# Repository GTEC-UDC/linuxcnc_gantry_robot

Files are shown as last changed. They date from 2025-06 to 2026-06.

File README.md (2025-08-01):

# LinuxCNC Gantry Robot System

A large high-precision 3-axis gantry robot system using [LinuxCNC](https://www.linuxcnc.org), integrated with [Mesa Electronics](https://store.mesanet.com/) interface cards and [igus® dryve D1](https://www.igus.eu/product/D1) motor controllers.

The system was developed from our [LinuxCNC motor control testbed](https://github.com/GTEC-UDC/linuxcnc_testbed), which ensured the main components of the system were able to work reliably.

The repository includes a **custom calibration solution** that leverages an existing [OptiTrack](https://optitrack.com/) motion capture system in the installation room to measure and compensate for errors in the gantry movement. Using this solution the gantry robot can achieve sub-centimeter precision across the entire work envelope.

<div align="center">






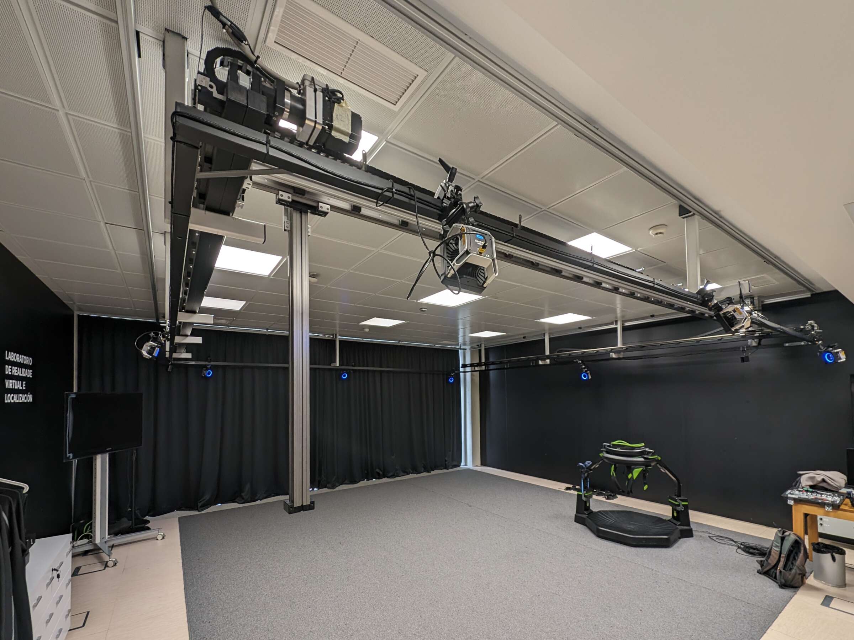
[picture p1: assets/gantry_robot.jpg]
Gantry Robot System


</div>

## Key Features

- **3-Axis Control**: X, Y, Z linear axes.
- **Large Work Envelope**: 5.3m (X) × 5.2m (Y) × 1m (Z) working volume.
- **Real-time Coordination**: Precise real-time motion using LinuxCNC with MESA interface cards and igus® dryve D1 motor controllers.
- **Closed Loop Control**: High-precision encoder feedback for accurate positioning using closed loop control.
- **Visual Status Indicators**: Custom LED status indicators.
- **Positioning calibration**: Software to analyze OptiTrack measurements and custom LinuxCNC kinematics module for compensation of positioning errors.
- **Heavy Duty**: Built with igus® self-lubricating linear units enabling lifelong operation of the moving parts without external lubrication.

## Documentation

The following documentation is provided in this repository:

- **Technical Documentation**: [Sphinx](https://www.sphinx-doc.org) documentation sources of the system documentation in [docs/](docs/). The documentation has been prepared to be built in HTML and PDF formats. To build the documentation follow the instructions below:

  1. **Prepare the environment**:

     ```bash
     cd docs
     uv venv && uv sync && source .venv/bin/activate
     ```

  2. **Build the documentation**:

     - HTML: `make html`

       The HTML documentation index file will be saved in `docs/build/html/index.html`.

     - PDF (requires a LaTeX installation with LuaLaTeX): `make latexpdf`

       The PDF file will be saved in `docs/build/latex/linuxcnc_gantry_robot.pdf`.

- **Electrical Installation**: KiCAD electrical schematics in [electrical_installation/schematics/](electrical_installation/schematics/).

## Positioning calibration

The gantry robot can be calibrated to compensate for positioning errors using an existing OptiTrack motion capture system in the installation room. For this, the repository provides the following software:

- **Custom `calibxyzkins` LinuxCNC Kinematics Module** in [linuxcnc/components/linuxcnc_calibrated_xyz_kins/](linuxcnc/components/linuxcnc_calibrated_xyz_kins/): compensates for the positioning errors in real-time
- **Calibration Analysis Software** in [calibration/](calibration/): Python scripts for processing the OptiTrack data and generating the calibration parameters

## Hardware Components

| Component | Model | Quantity | Function |
|---|---|---|---|
| **Control Computer** | PC running [LinuxCNC](https://www.linuxcnc.org) | 1 | Real-time motor coordination |
| **Motor Controllers** | [igus® dryve D1](https://www.igus.eu/product/D1) | 4 | Individual motor control |
| **Main Interface** | [MESA 7I96S](https://store.mesanet.com/index.php?route=product/product&product_id=374) | 1 | Ethernet-LinuxCNC bridge and stepper motor control |
| **I/O Expansion** | [MESA 7I77](https://store.mesanet.com/index.php?route=product/product&product_id=120) | 1 | Analog control for brushless motors and I/O signals |
| **X-Axis Motor** | [igus® MOT-EC-86-C-I-A](https://www.igus.eu/product/MOT-EC-86-C-I-A) | 2 | NEMA 34 brushless with 1000 PPR encoder |
| **Y-Axis Motor** | [igus® MOT-EC-86-C-I-A](https://www.igus.eu/product/MOT-EC-86-C-I-A) | 1 | NEMA 34 brushless with 1000 PPR encoder |
| **Z-Axis Motor** | [igus® MOT-AN-S-060-035-060-M-C-AAAC](https://www.igus.eu/product/MOT-AN-S-060-035-060-M-C-AAAC) | 1 | NEMA 24 stepper with 500 PPR encoder |
| **Emergency Stop** | Push-button with NO/NC contacts | 1 | System safety shutdown |
| **Limit Switches** | [igus® proximity switch](https://www.igus.eu/product/drylin_E_ini_kits_plastic_housing) | 4 | Position boundary detection |
| **48V Power Supply** | [MEAN WELL SDR-960-48](https://www.meanwell.com/webapp/product/search.aspx?prod=SDR-960) | 3 | Brushles motors power |
| **24V Power Supply** | [MEAN WELL SDR-240-24](https://www.meanwell.com/webapp/product/search.aspx?prod=SDR-240) | 1 | Stepper motor power |
| **24V Power Supply** | Generic power supply | 1 | igus® Drive D1 logic and MESA 7I77 field power |
| **5V Power Supply** | [MEAN WELL MDR-20-5](https://www.meanwell.com/webapp/product/search.aspx?prod=MDR-20) | 1 | MESA 7I77 field I/O logic power |

## System Architecture

Prototype System

## Repository Structure

```txt
gantry-robot/
├── README.md                    # This file
├── assets/                      # Pictures and videos
├── docs/                        # Technical documentation
├── igus-dryve/                  # igus® dryve D1 configuration files
├── linuxcnc/                    # LinuxCNC configuration files
│   ├── configs/                 # Machine configurations
│   └── components/              # Custom LinuxCNC components
├── calibration/                 # Calibration code and measurements
│   ├── src/                     # Python analysis and calibration tools
│   └── measurements/            # Gantry robot and OptiTrack measurements
└── electrical_installation/     # Electrical documentation
    ├── schematics/              # KiCAD electrical diagrams
    └── photos/                  # Electrical installation photos
```

## License

This project contains multiple components with different licenses.

### General License (unless otherwise specified)

<a rel="license" href="http://creativecommons.org/licenses/by-sa/4.0/">

</a>

[LinuxCNC Gantry Robot System](https://github.com/GTEC-UDC/linuxcnc_gantry_robot) © 2025 by [Tomás Domínguez Bolaño](https://orcid.org/0000-0001-7470-0315), [Valentín Barral Vales](https://orcid.org/0000-0001-8750-7960), [Carlos José Escudero Cascón](https://orcid.org/0000-0002-3877-1332), and [José Antonio García Naya](https://orcid.org/0000-0002-1944-4678) (CITIC Research Center, University of A Coruña, Spain) is licensed under [Creative Commons Attribution-ShareAlike 4.0 International](https://creativecommons.org/licenses/by-sa/4.0/) (CC BY-SA 4.0). To view a copy of this license, see the [LICENSE](LICENSE) file or visit <https://creativecommons.org/licenses/by-sa/4.0/>.

### Documentation License ([docs/](docs/))

Copyright © 2000-2022 LinuxCNC.org\
Copyright © 2025 Tomás Domínguez Bolaño, Valentín Barral Vales, Carlos José Escudero Cascón, and José Antonio García Naya.

Permission is granted to copy, distribute and/or modify this document
under the terms of the GNU Free Documentation License, Version 1.3
or any later version published by the Free Software Foundation;
with no Invariant Sections, no Front-Cover Texts, and no Back-Cover Texts.
A copy of the license is included in the section entitled "GNU Free Documentation License".

### Software Licenses

- **LinuxCNC Components** (`linuxcnc/components/`): [GPL v2 or later](https://www.gnu.org/licenses/old-licenses/gpl-2.0.html)
- **Calibration Source Code** (`calibration/src/`): [MIT License](https://opensource.org/licenses/MIT)

## Acknowledgments

This work has been supported by grant PID2022-137099NB-C42 (MADDIE) and by project TED2021-130240B-I00 (IVRY) funded by MCIN/AEI/10.13039/501100011033 and the European Union NextGenerationEU/PRTR.

<div align="center">
  Acknowledgements logos
</div>

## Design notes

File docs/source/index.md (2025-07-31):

# {{project}}

A large high-precision 3-axis gantry robot system using [LinuxCNC](https://www.linuxcnc.org), integrated with [Mesa Electronics](https://store.mesanet.com/) interface cards and [igus® dryve D1](https://www.igus.eu/product/D1) motor controllers.

The system was developed from our [LinuxCNC motor control testbed](https://github.com/GTEC-UDC/linuxcnc_testbed), which ensured the main components of the system were able to work reliably.

The system includes a custom calibration solution that leverages an existing [OptiTrack](https://optitrack.com/) motion capture system in the installation room to measure and compensate for errors in the gantry movement. Using this solution the gantry robot can achieve sub-centimeter precision across the entire work envelope.

---

Copyright (C) 2000-2022 LinuxCNC.org\
Copyright (C) 2025 Tomás Domínguez Bolaño, Valentín Barral Vales, Carlos José Escudero Cascón, and José Antonio García Naya.

Permission is granted to copy, distribute and/or modify this document
under the terms of the GNU Free Documentation License, Version 1.3
or any later version published by the Free Software Foundation;
with no Invariant Sections, no Front-Cover Texts, and no Back-Cover Texts.
A copy of the license is included in the section entitled "GNU Free Documentation License".

---

This work has been supported by grant PID2022-137099NB-C42 (MADDIE) and by project TED2021-130240B-I00 (IVRY) funded by MCIN/AEI/10.13039/501100011033 and the European Union NextGenerationEU/PRTR.

:::{ext-image} images/logos/ack_logos.*
:width-html: 700px
:name: fig:ack_logos
:::

:::{only} html
<!-- -->
---
<!-- -->
:::

:::{toctree}
:maxdepth: 2
:numbered:
:caption: Table of Contents

doc/01_introduction/introduction.md
doc/02_igus_dryve_d1/00_index.md
doc/03_linuxcnc/00_index.md
doc/04_error_analysis_calibration/00_index.md
doc/05_calibxyzkins_module/00_index.md
:::

:::{raw} latex
% Do not show section numbers for the following sections in latex
\setcounter{secnumdepth}{-1}
:::

:::{toctree}
:maxdepth: 1

fdl-1.3.md
bibliography.md
:::

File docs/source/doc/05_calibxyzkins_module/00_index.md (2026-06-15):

(sec:calibxyzkins_module)=

# calibxyzkins - Calibrated XYZ Kinematics Module for LinuxCNC

The `calibxyzkins` module extends the standard LinuxCNC trivial kinematics module `trivkins` by applying a mathematical correction to compensate for systematic positioning errors in gantry robots and similar cartesian machines. This is particularly useful for correcting:

- Mechanical inaccuracies in manufacturing or assembly
- Structural deformations under load
- Non-perpendicular axes alignment
- Position-dependent errors

## Coordinate Transformation

The module implements a coordinate transformation that corrects the relationship between joint positions and actual machine coordinates using both linear and quadratic terms:

$[x', y', z']^T = \mathbf{A} [x, y, z]^T + \mathbf{B} [x^2, y^2, z^2]^T + \mathbf{c}$

Where:

- $(\cdot)^T$: Transpose operator
- $\mathbf{A}$: 3×3 linear transformation matrix (scaling, rotation, shear, etc.)
- $\mathbf{B}$: 3×3 quadratic transformation matrix (corrects non-linear distortions)
- $\mathbf{c}$: 3×1 offset vector (constant position offset)
- $x, y, z$: joint positions
- $x', y', z'$: axes coordinates

The default values of the parameters are:

- $\mathbf{A}$: 3x3 identity matrix
- $\mathbf{B}$: all zeros
- $\mathbf{c}$: all zeros

## Installation

Prerequisites:

- LinuxCNC development environment
- Standard build tools (make, gcc)

To build the module, run:

```bash
cd linuxcnc/components/linuxcnc_calibrated_xyz_kins
make
```

To install the module system-wide, run:

```bash
sudo make install
```

### Loading the Module

The module can be loaded as any other HAL component. Depending on the machine configuration, the `coordinates` and `kinstype` parameters can be used to specify the axis-to-joint mapping.

Examples:

- Basic usage (equivalent to `trivkins`):

  ```hal
  loadrt calibxyzkins
  ```

- Specify coordinate mapping:

  ```hal
  loadrt calibxyzkins coordinates=xyz
  ```

- Gantry configuration with duplicated Y axis:

  ```hal
  loadrt calibxyzkins coordinates=xyyz kinstype=B
  ```

## Module Parameters

- `coordinates`

  Specifies the axis-to-joint mapping, as in `trivkins`:
  
  - **coordinates=xyz**: Standard 3-axis mapping (X→joint0, Y→joint1, Z→joint2)
  - **coordinates=xyyz**: Gantry with dual Y motors (X→joint0, Y→joint1&joint2, Z→joint3)
  - **coordinates=xyzabc**: 6-axis machine. Note that calibration is only applied to the X, Y, and Z axes.

- `kinstype`

  Specifies the kinematics type, as in `trivkins`:
  
  - **kinstype=1**: KINEMATICS_IDENTITY (default)
  - **kinstype=B**: KINEMATICS_BOTH
  - **kinstype=F**: KINEMATICS_FORWARD_ONLY
  - **kinstype=I**: KINEMATICS_INVERSE_ONLY

## HAL Parameters

**Calibration Matrix A (Linear Terms)**:

- `calibxyzkins.calib-a.xx` (float, RW, default: 1.0)
- `calibxyzkins.calib-a.xy` (float, RW, default: 0.0)
- `calibxyzkins.calib-a.xz` (float, RW, default: 0.0)
- `calibxyzkins.calib-a.yx` (float, RW, default: 0.0)
- `calibxyzkins.calib-a.yy` (float, RW, default: 1.0)
- `calibxyzkins.calib-a.yz` (float, RW, default: 0.0)
- `calibxyzkins.calib-a.zx` (float, RW, default: 0.0)
- `calibxyzkins.calib-a.zy` (float, RW, default: 0.0)
- `calibxyzkins.calib-a.zz` (float, RW, default: 1.0)

**Calibration Matrix B (Quadratic Terms)**:

- `calibxyzkins.calib-b.xx` (float, RW, default: 0.0)
- `calibxyzkins.calib-b.xy` (float, RW, default: 0.0)
- `calibxyzkins.calib-b.xz` (float, RW, default: 0.0)
- `calibxyzkins.calib-b.yx` (float, RW, default: 0.0)
- `calibxyzkins.calib-b.yy` (float, RW, default: 0.0)
- `calibxyzkins.calib-b.yz` (float, RW, default: 0.0)
- `calibxyzkins.calib-b.zx` (float, RW, default: 0.0)
- `calibxyzkins.calib-b.zy` (float, RW, default: 0.0)
- `calibxyzkins.calib-b.zz` (float, RW, default: 0.0)

**Calibration Vector c (Offset Terms)**:

- `calibxyzkins.calib-c.x` (float, RW, default: 0.0)
- `calibxyzkins.calib-c.y` (float, RW, default: 0.0)
- `calibxyzkins.calib-c.z` (float, RW, default: 0.0)

**Joint Limits**:

- `calibxyzkins.min-limit.x` (float, RW, default: -∞)
- `calibxyzkins.min-limit.y` (float, RW, default: -∞)
- `calibxyzkins.min-limit.z` (float, RW, default: -∞)
- `calibxyzkins.max-limit.x` (float, RW, default: +∞)
- `calibxyzkins.max-limit.y` (float, RW, default: +∞)
- `calibxyzkins.max-limit.z` (float, RW, default: +∞)

## HAL Pins

**Inverse Kinematics Solver Settings**:

- `calibxyzkins.max-iter` (u32, IO, default: 10)
  - Maximum number of Newton-Raphson iterations for the inverse kinematics.
- `calibxyzkins.tol` (float, IO, default: 1e-3)
  - Convergence tolerance for the inverse kinematics solver.

## Inverse Kinematics

The module uses the Newton-Raphson method to solve the inverse kinematics problem iteratively:

1. Initialize the $3 \times 1$ vector of joint positions $\mathbf{x}$ to the target position $\mathbf{x'}$ (bounded by joint limits if specified)
2. Perform Newton-Raphson iterations until convergence or max iterations reached:
   1. Compute residual: $\mathbf{r} = \mathbf{A} \, \mathbf{x} + \mathbf{B} \, \mathbf{x}^2 + \mathbf{c} - \mathbf{x'}$
   2. Return if convergence reached ($\|\mathbf{r}\|_2 < \text{tolerance}$).
   3. Compute Jacobian: $\mathbf{J} = \mathbf{A} + 2 \, \mathbf{B} \, \text{diag}(\mathbf{x})$
   4. Update joints: $\mathbf{x} := \mathbf{x} - \mathbf{J}^{-1} \mathbf{r}$

## Debugging

Verbose output of the inverse kinematics solver can be enabled by compiling the code with the `CALIB_XYZ_INVERSE_PRINT_ITER` macro defined.

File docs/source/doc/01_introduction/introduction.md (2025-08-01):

# Introduction

The gantry robot uses LinuxCNC as its control platform, integrated with Mesa Electronics interface boards and igus® dryve D1 motor controllers. It provides a displacement range of 5.3m (X) × 5.2m (Y) × 1m (Z), with a total work volume of approximately 6m (X) × 6m (Y) × 2m (Z). {numref}`fig:installation` shows a photograph of the gantry robot structure. The system diagram is shown in {numref}`fig:system_diagram`.

This system was developed from our LinuxCNC testbed (<https://github.com/GTEC-UDC/linuxcnc_testbed>). The system wiring diagram, detailing all components and their interconnections, is available in the {{project_url_link}}. Below, we detail the system's configuration, including the boards and components used.

:::{ext-figure} images/gantry_robot.*
:width-html: 75%
:name: fig:installation

Gantry robot structure.
:::

:::{ext-figure} images/system_diagram.*
:width-html: 75%
:name: fig:system_diagram

Gantry robot system diagram.
:::

## LinuxCNC

LinuxCNC, formerly known as the {{EMC}}, is a software system designed for the computer control of various machine tools, such as milling machines and lathes, as well as robots like PUMA and SCARA, and other computer-controlled machinery with up to nine axes. LinuxCNC is free, open-source software. Current versions are fully licensed under the [{{GPL}}](https://www.gnu.org/licenses/gpl.html) and [{{LGPL}}](https://gnu.org/licenses/lgpl.html).

In our system, LinuxCNC communicates with the igus® dryve D1 controllers via the MESA 7I96S and 7I77 boards. LinuxCNC is responsible for coordinating the operation of all motors, providing precise, real-time control over the system.

Detailed information on LinuxCNC's operation and configuration can be found in {numref}`sec:linuxcnc`.

(sec:hardware)=

## System Hardware

The following section describe the different hardware components of the system, such as the motor controllers, interface boards, motors, and safety systems. {numref}`fig:electrical_overview` belowshows the electrical cabinet and rack that house the interface boards, motor controllers, and power supplies.

:::{ext-figure} images/electrical_cabinet_and_rack.*
:width-html: 75%
:name: fig:electrical_overview

Electrical cabinet (left) containing the MESA interface boards and rack (right) containing the motor controllers and power supplies.
:::

### Main Components

- **Control Computer**: PC running [LinuxCNC](https://www.linuxcnc.org) for real-time motor coordination

- **4 Motor Controllers** [igus® dryve D1](https://www.igus.eu/product/D1): igus® dryve D1 can be used for controlling stepper, DC, and brushless motors in industrial and automation applications. The igus® dryve D1 supports the following communication methods with control systems:

  - **CANopen**: A communication protocol widely used in industrial automation systems, built upon the CAN bus (ISO 11898) standard.
  - **Modbus TCP**: A communication protocol extensively employed in industrial applications for data transmission over Ethernet networks using the TCP protocol.
  - **Analog and Digital Signals**: In addition to network communication options, the igus® dryve D1 can receive analog and digital signals for direct control.

    In this system, we communicate with the igus® dryve D1 controllers using MESA 7I96S and 7I77 boards using digital and analog signals. This setup enables LinuxCNC to have precise, real-time control over the motors' operation.

{numref}`fig:rack_interior` below shows the interior of the rack containing the four igus® dryve D1 motor controllers and the power supplies.

:::{ext-figure} images/rack.*
:width-html: 75%
:name: fig:rack_interior

Interior view of the rack showing the igus® dryve D1 motor controllers and power supplies.
:::

### Interface Boards

- **Main Board** [MESA 7I96S](https://store.mesanet.com/index.php?route=product/product&product_id=374): This board is the primary hardware interface between LinuxCNC and the igus® dryve D1 controllers. It connects to the computer running LinuxCNC via an Ethernet connection. Its main functions include:

  - Controlling the stepper motor by sending step and direction signals to its designated igus® dryve D1 controller.
  - Receiving input signals from limit switches.

- **Expansion Board** [MESA 7I77](https://store.mesanet.com/index.php?route=product/product&product_id=120): This board connects to the 7I96S board via a 25-pin flat cable. Its primary functions are:

  - Controlling the brushless motor by sending an analog speed signal to its corresponding igus® dryve D1 controller.
  - Receiving position feedback signals from motor encoders.
  - Receiving warning and error signals from the controllers.
  - Receiving the emergency stop signal when the emergency stop switch is activated.

{numref}`fig:electrical_cabinet` below shows the MESA 7I96S and 7I77 boards installed in the electrical cabinet.

:::{ext-figure} images/electrical_cabinet.*
:width-html: 75%
:name: fig:electrical_cabinet

Interior view of the electrical cabinet showing the MESA 7I96S and 7I77 interface boards.
:::

### Motors and Actuators

- **X-axis Motors**: 2 × [igus® MOT-EC-86-C-I-A](https://www.igus.eu/product/MOT-EC-86-C-I-A) - NEMA 34 brushless with integrated 1000 {{PPR}} encoder. A 10:1 reduction gear was installed on the motor shaft.

- **Y-axis Motor**: 1 × [igus® MOT-EC-86-C-I-A](https://www.igus.eu/product/MOT-EC-86-C-I-A) - NEMA 34 brushless with integrated 1000 {{PPR}} encoder. A 10:1 reduction gear was installed on the motor shaft.

- **Z-axis Motor**: 1 × [igus® MOT-AN-S-060-035-060-M-C-AAAC](https://www.igus.eu/product/motors-and-gears) - NEMA 24 stepper with 500 {{PPR}} encoder.

### Safety Systems and Sensors

- **Emergency Stop Switch**: This switch has both a normally closed and a normally open contact.

- **Limit Sensors**: 4 × igus® inductive sensors for position limit detection.

- **LED Indicators**: Custom indicators with red, yellow, and green LEDs, which provide a visual display of the system's status.

### Power Supply

- **48V Power Supplies**: 3 × [MEAN WELL SDR-960-48](https://www.meanwell.com/webapp/product/search.aspx?prod=SDR-960) for brushless motor power.
- **24V Power Supply**: 1 × [MEAN WELL SDR-240-24](https://www.meanwell.com/webapp/product/search.aspx?prod=SDR-240) for stepper motor power.
- **Additional 24V Power Supply**: For igus® dryve D1 logic and MESA 7I77 field power.
- **5V Power Supply**: [MEAN WELL MDR-20-5](https://www.meanwell.com/webapp/product/search.aspx?prod=MDR-20) for MESA 7I77 field I/O logic.

### Linear Units

The system is built with igus® self-lubricating linear units that enable lifetime operation of moving parts without external lubrication. The linear units details are the following:

- **X and Y axes**: [igus® ZLW-20120/20200](https://www.igus.eu/drive-technology/linear-axes-with-toothed-belts/technical-data) linear axes with toothed belts. The feed rate is 144 mm/rev.
- **Z axis**: [igus® SAW-1660](https://www.igus.eu/product/20908?artNr=SLW-1660-xxx) linear axis with lead screws. The feed rate is 4 mm/rev.

## Calibration System

This project includes the following calibration components:

- **Custom LinuxCNC kinematic module** `calibxyzkins` in `linuxcnc/components/linuxcnc_calibrated_xyz_kins`: enables real-time positioning error compensation.
- **Calibration analysis software** in `calibration/`: Python-based tools for processing OptiTrack data and generating calibration parameters.

This solution enables the gantry robot to achieve sub-centimeter precision throughout the entire working volume of 5.3m × 5.2m × 1m.

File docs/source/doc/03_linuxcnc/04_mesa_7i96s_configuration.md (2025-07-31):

# MESA 7I96S Board Configuration

## Flashing the Firmware

:::{note}
This process has already been completed and does not need to be repeated; it is described here solely for documentation purposes. For more information on configuring the MESA 7I96S board, please consult its manual.
:::

The MESA 7I96S board can be used standalone with its standard configuration. However, to use it with the MESA 7I77 board, we must flash the FPGA with the appropriate firmware. Various firmwares for the 7I96S board are available on the MESA website at <http://www.mesanet.com/software/parallel/7i96s.zip>.

To use the MESA 7I96S board with the MESA 7I77 board, we will use the `7i96s_7i77d.bin` firmware. First, power the board with 5 V via its P4 connector and connect it to the PC using an Ethernet cable. By default, the board's IP address is `192.168.1.121`. To verify connectivity, execute the following command:

```text
mesaflash -device 7i96s -addr 192.168.1.121
```

If successful, the `mesaflash` utility will detect the board and respond with the following output:

```text
ETH device 7I96S at ip=192.168.1.121
```

Finally, to flash the firmware to the board, execute the following command:

```text
mesaflash -device 7i96s -addr 192.168.1.121 -write 7i96s_7i77d.bin
```

## Network Configuration

The Beelink EQR6 mini computer used in our gantry robot system has two Ethernet ports, which allows for a dedicated network connection to the MESA 7I96S board. One port is used to connect the PC to the local network, while the other port is used for a direct connection to the MESA card. This setup provides isolation and dedicated bandwidth for the real-time communication with the motion control system.

## IP Address

The MESA 7I96S board has three options for setting the IP address: a default IP (`192.168.1.121`), an IP read from the EEPROM, and IP acquisition via the BOOTP network protocol. These options are selected using jumpers `W4` and `W5`, located on the bottom left of the board as shown in {numref}`fig:mesa_ip_selection`.

:::{figure} images/mesa/mesa_7i96s_left.*
:name: fig:mesa_ip_selection
:width: 80%

View of the left side of the MESA 7I96S board installed in the gantry robot system.
:::

The available IP configuration options are detailed in {numref}`tab:mesa_ip_selection`. Specifically, note the following:

- When jumpers `W4` and `W5` are in the (down, up) position, the IP address will be read from the EEPROM. The default IP address in the EEPROM is 10.10.10.10. This IP address can be changed using the `mesaflash` utility. For example, to set the IP in the EEPROM to 10.10.10.100, you would execute the following command:

  ```text
  mesaflash -device 7i96s -addr 192.168.1.121 -set ip=10.10.10.100
  ```

- When jumpers `W4` and `W5` are in the (up, up) position, the IP address will be set to 192.168.1.121, and the board will boot using the fallback configuration (see {numref}`sec:mesa7i96s_fallback`).

:::{csv-table} IP address configuration options on the MESA 7I96S board using jumpers ``W4`` and ``W5``.
:name: tab:mesa_ip_selection
:widths: auto
:header: W4, W5, IP Address

Down, Down, 192.168.1.121
Down, Up, Read from EEPROM
Up, Down, Obtained via BOOTP
Up, Up, 192.168.1.121 and use fallback conf.
:::

In our gantry robot system, jumpers `W4` and `W5` have been set to the (down, down) position, as shown in {numref}`fig:mesa_ip_selection`.

(sec:mesa7i96s_fallback)=

## Fallback Configuration

The MESA 7I96S board's flash memory contains two images: a main image and a fallback image. If the primary image becomes corrupted, the FPGA will load the fallback configuration, allowing a new main image to be written. Otherwise, the memory would have to be programmed via JTAG.

It is possible to force the board to boot using the fallback configuration by setting the IP selection jumpers `W4` and `W5` to the (up, up) position. In this boot mode, the card's IP address will be set to 192.168.1.121.

(sec:mesa7i96s_cable_power)=

## Expansion Connector 5 V Power Supply

The MESA 7I96S board has the capability to supply 5V power to the board connected to its expansion connector (P1), which in our case is the MESA 7I77. This option is controlled by jumper `W6`, located on the bottom of the board to the left of the expansion connector, as shown in {numref}`fig:mesa_ip_selection`. The settings are as follows:

- When jumper `W6` is in the up position, the MESA 7I96S board will provide power to the MESA 7I77 board through the expansion connector.
- When jumper `W6` is in the down position, the MESA 7I96S board will not provide power through the expansion connector; in this case, external power must be supplied to the MESA 7I77 board.

In our gantry robot system, the latter option was chosen, with jumper `W6` configured in the down position, as seen in {numref}`fig:mesa_ip_selection`. The MESA 7I77 board must also be configured appropriately, as explained in {numref}`sec:mesa7i77_power`.

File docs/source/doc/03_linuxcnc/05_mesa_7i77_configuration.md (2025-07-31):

# MESA 7I77 Board Configuration

(sec:mesa7i77_power)=

## 5 V Main Power

The MESA 7I77 board can draw its main 5V power either from the MESA 7I96S board or through its `TB1` connector. This power is needed for the encoders, analog outputs, and the RS-422 interface. The main power mode for the MESA 7I77 is selected using jumper `W5` as follows:

1. If `W5` is in the left position, power is supplied via the MESA 7I96S board. In this case, jumper `W6` on the MESA 7I96S board must be set to the up position.
2. If `W5` is in the right position, power must be supplied to the board externally through the `TB1` connector. In this case, jumper `W6` on the MESA 7I96S board must be set to the down position to prevent it from supplying power to the daughterboard.

:::{attention}
Supplying power to the MESA 7I77 board through the `TB1` connector with jumper `W5` in the left position can potentially damage the MESA 7I77 board, the MESA 7I96S board, the connection cable, and even the PC.
:::

In our gantry robot system, we chose to power the MESA 7I77 board via the `TB1` connector; therefore:

- Jumper `W6` on the MESA 7I96S board has been set to the down position, as shown in {numref}`fig:mesa_ip_selection`.
- Jumper `W5` on the MESA 7I77 board has been set to the right position, as shown in {numref}`fig:mesa7i77_left`.

:::{figure} images/mesa/mesa_7i77_left.*
:name: fig:mesa7i77_left

View of the left side of the MESA 7I77 board installed in the gantry robot system.
:::

## Digital Inputs and Outputs Power

In addition to the 5V main power, the MESA 7I77 board also requires supplementary power for its digital inputs and outputs through the `TB2` connector (see Figures {numref}`%s <fig:installation>` and {numref}`%s <fig:mesa7i77_right>`). The pinout for the `TB2` connector is provided in {numref}`tab:mesa7i77_tb2`.

:::{csv-table} Connections of the ``TB2`` connector of the MESA 7I77 board.
:name: tab:mesa7i77_tb2
:widths: auto
:header: Pin, Signal, Function

1 (bottom), `VFIELD`, `FIELD POWER`
2, `VFIELD`, `FIELD POWER`
3, `VFIELD`, `FIELD POWER`
4, `VFIELD`, `FIELD POWER`
5, `VIN`, `FIELD I/O LOGIC POWER`
6, Not connected, --
7, Not connected, --
8 (top), Ground, Reference of `VIN` & `VFIELD`
:::

As indicated in {numref}`tab:mesa7i77_tb2`, the board requires two power inputs in this configuration:

- `VFIELD`: This input supplies power to the outputs and determines the logic levels of the inputs, with a range of 5 V to 28 V.
- `VIN`: This input provides power to the input/output logic, with a range of 8 V to 32 V.

If `VFIELD` is between 8 V and 28 V, the same source can be used to power `VIN`. The board includes jumper W1, which, when placed in the left position, connects `VIN` with `VFIELD`. To use `VFIELD` values outside the `VIN` range (e.g., 5 V), you must place W1 in the right position to disconnect `VIN` and `VFIELD`, allowing for separate power supplies for `VIN` and `VFIELD`.

:::{attention}
The voltage at `VFIELD` must have a maximum rise rate of 10 V/ms to prevent damage to the board. This is a limitation of MOSFET transistors {cite}`toshiba2018impacts, toshiba2018mosfets, nexperia2023power, bai2003analysis`. Therefore, `VFIELD` must be connected directly to the power supply without using switches in the circuit.
:::

As stated in {numref}`sec:page_input_outputs`, the MESA 7I96S board can only use 5 V logic for step and direction signals. Therefore, the logic for both the igus® dryve D1 controllers and the MESA 7I77 board must also be 5 V. Thus, in our gantry robot system, jumper `W1` on the MESA 7I77 board has been set to the right position, the `VIN` input to 24 V, and the `VFIELD` input to 5 V, as shown in {numref}`fig:mesa7i77_right`.

::: {figure} images/mesa/mesa_7i77_right.*
:name: fig:mesa7i77_right

View of the right side of the MESA 7I77 board installed in the gantry robot system.
:::

## Encoder Input Modes

The MESA 7I77 board has six encoder inputs, each with individual A, B, and Z inputs. These inputs can be configured to operate with either differential or single-ended signals. Each encoder has three jumpers to configure the mode for its individual A, B, and Z inputs. Setting a jumper to the right position selects differential mode, while setting it to the left position selects single-ended mode. The list of jumpers for the individual inputs of each encoder is provided in {numref}`tab:encoder_jumpers`.

:::{table} Encoder configuration jumpers.
:name: tab:encoder_jumpers
:widths: auto

| Encoder | Jumper A  | Jumper B | Jumper C |
| --- | --- | --- | --- |
| 0 | W21 | W19 | W17 |
| 1 | W15 | W13 | W10 |
| 2 | W8 | W6 | W2 |
| 3 | W22 | W20 | W18 |
| 4 | W16 | W14 | W11 |
| 5 | W9 | W7 | W3 |
:::

In our gantry robot system each of the 4 motors has a differential encoder. Therefore, we set encoders 0 to 3 on the MESA 7I77 board to differential mode. {numref}`fig:mesa7i77_left` shows the location of the jumpers for encoders 0 to 3 on the MESA 7I77 board.

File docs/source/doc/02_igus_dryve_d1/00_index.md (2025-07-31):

# igus® dryve D1 Controllers

:::{important}
For the gantry robot development we used the igus® dryve D1 controllers with firmware version `dryve-D1-1-20240927` and their operating manual with version `3.1`.
:::

In this section, we will detail the configuration of the igus® dryve D1 controllers for our gantry robot. The robot uses 4 motors, each with its own controller:

- **X1 axis**: igus® MOT-EC-86-C-I-A brushless motor with 1000 {{PPR}} encoder and 10:1 reduction gear.
- **X2 axis**: identical to X1
- **Y axis**: identical to X1 and X2
- **Z axis**: igus® MOT-AN-S-060-035-060-M-C-AAAC stepper motor with 500 {{PPR}} encoder.

To configure each controller, connect it to a PC via an Ethernet cable. If you do not know a controller's IP address, you can find it by powering on the device or reconnecting the Ethernet cable. In either case, the controller will sequentially display its IP address, digit by digit, on the seven-segment display located on its front panel.

Once connected, open a web browser and enter the IP address of the controller you wish to configure. This will grant access to the controller's web-based configuration interface. The following sections describe the controller's configuration parameters and the values to be applied for both the brushless motors (X1, X2, Y) and the stepper motor (Z). For more comprehensive information, it is recommended to consult the official controller manual.

:::{toctree}
:maxdepth: 2
:caption: Table of Contents

01_start_page.md
02_motor_page.md
03_axis_page.md
04_communication_page.md
05_inputs_outputs_page.md
06_drive_profile_page.md
07_oscilloscope_page.md
:::

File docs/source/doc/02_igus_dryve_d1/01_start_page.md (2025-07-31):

(sec:conf_start)=

# "Start" Page

The "Start" configuration page, shown below in {numref}`fig:conf_x1_start`, contains various general settings. Specifically, we will configure the following options for all the controllers:

- **Measuring system**: Metric, Millimeter
- **Movement type**: Linear
- **Time units**: Seconds

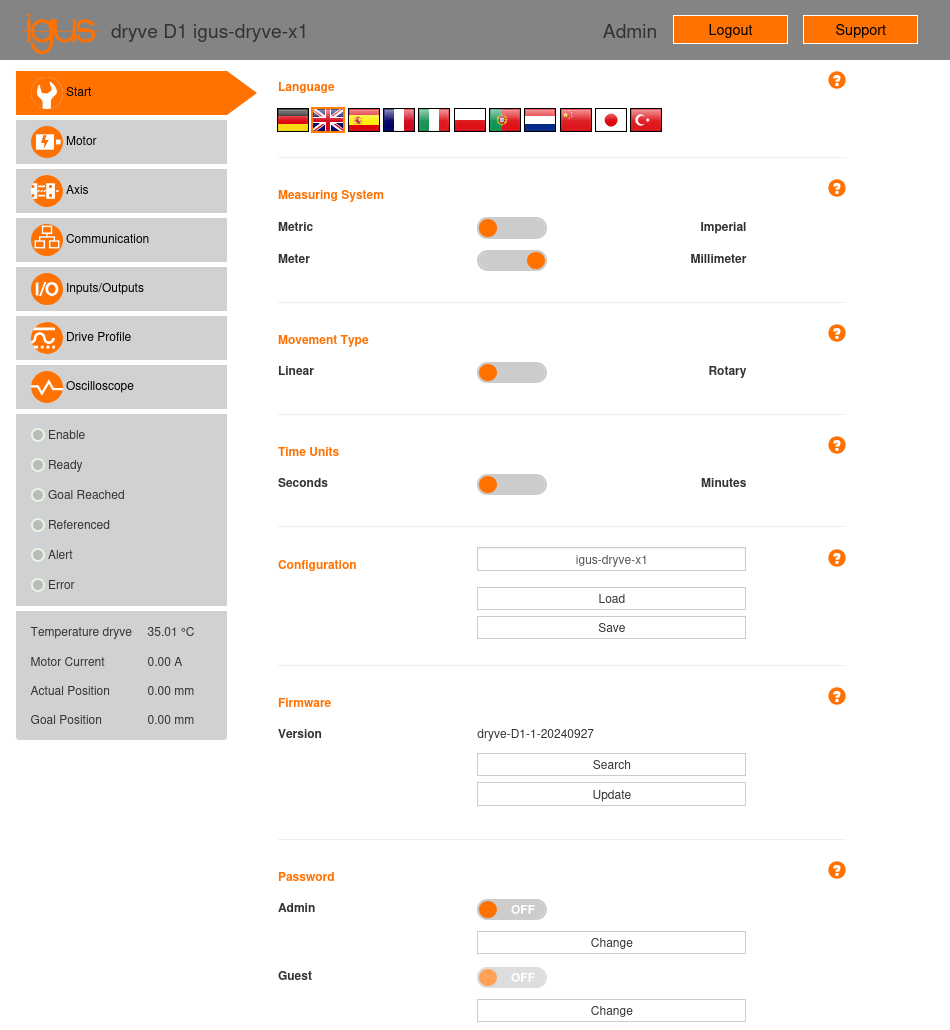
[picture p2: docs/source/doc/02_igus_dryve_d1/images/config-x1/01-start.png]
:::{figure} images/config-x1/01-start.png
:name: fig:conf_x1_start

Initial configuration page of the X1 motor controller.
:::

Additionally, this page includes the following sections:

- **Configuration**: This section allows you to save the current controller configuration to a file and load a configuration from a file. Once the controller configuration is defined, it is recommended to use this functionality to save it.
- **Firmware**: This section enables updating the controller firmware. The "Search" button directs you to the URL for downloading the latest firmware version. The "Update" button allows you to load the firmware file from your disk to update the controller.
- **Password**: This section allows you to set a password for "Admin" and "Guest" users. These users can be activated or deactivated using their respective switches. If both users are deactivated (the default setting), the user interface is accessed with the "Admin" user. The "Guest" user can only be activated if the "Admin" user has been previously activated.

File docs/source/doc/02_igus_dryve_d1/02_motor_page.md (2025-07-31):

# "Motor" Page

The "Motor" configuration page is shown below in {numref}`fig:conf_x1_motor`. The following sections describe the various available options and their appropriate settings for our gantry robot.

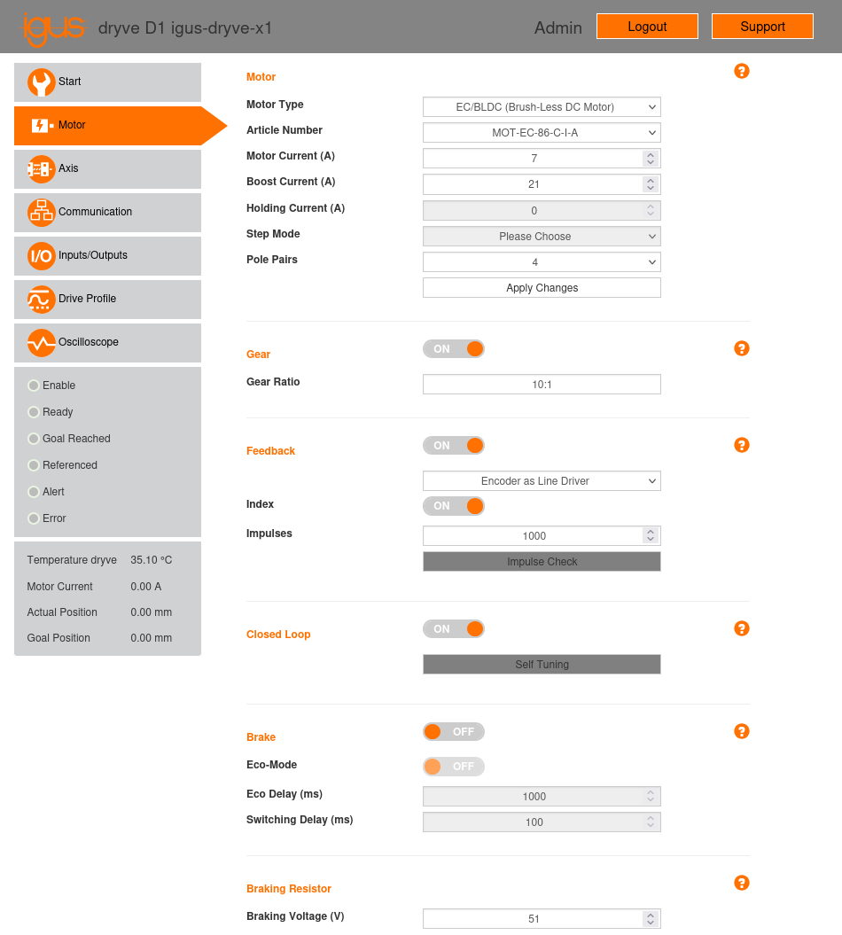
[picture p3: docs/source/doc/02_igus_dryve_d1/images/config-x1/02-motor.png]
:::{figure} images/config-x1/02-motor.png
:name: fig:conf_x1_motor

"Motor" configuration page of the X1 motor controller.
:::

## Motor Configuration Summary

{numref}`tab:motor_config_summary` below summarizes the configuration parameters for the motors in our gantry robot setup:

:::{tabularcolumns} l\R{0.35}\R{0.35}
:::

:::{csv-table} Motor configuration summary for the gantry robot.
:name: tab:motor_config_summary
:widths: auto
:header: Parameter,Value (X1/X2/Y),Value (Z)
:class: longtable align-col2-r align-col3-r

**Motor**,,
Motor Type,EC/BLDC,ST
Article Number,MOT-EC-86-C-I-A,MOT-AN-S-060-035-060-M-C-AAAC
Motor Current (A),7,3.2
Boost Current (A),21,3.2
Pole Pairs,4,N/A
Step Mode,N/A,1/32
Step Angle (°),N/A,1.8
**Gear**,,
Gear Ratio,10:1,N/A
**Feedback**,,
Type,Encoder as a Line Driver,Encoder as a Line Driver
Index,ON,ON
Impulses,1000,500
**Braking Resistor**,,
Braking Voltage (V),51,N/A
:::

(sec:motor_motor)=

## Motor

- **Motor Type**: The type of motor. Select "EC/BLDC (Brush-Less DC Motor)" for the brushless motors (X1, X2, Y) and "ST (Stepper Motor)" for the stepper motor (Z).

- **Article Number**: For igus® motors, you can select the motor's article number. In that case, parameters such as "Motor Current," "Boost Current," "Holding Current," "Step Angle," and "Pole pairs," along with other settings in the "Gear," "Feedback," "Closed Loop," "Brake," and "Braking Resistor" sections, will be automatically populated with default values corresponding to the selected motor model.

  In our gantry robot, we selected the article numbers of the motors used:

  - **Brushless motors (X1, X2, Y)**: MOT-EC-86-C-I-A
  - **Stepper motor (Z)**: MOT-AN-S-060-035-060-M-C-AAAC

- **Motor Current (A)**: Defines the maximum permissible continuous current for the motor during sustained movements, i.e.,excluding acceleration and deceleration phases (refer to the "Boost Current" option for those cases). Values can range from 0 A to 7 A.

  :::{important}
  This parameter must be less than the maximum current that the power supply can provide, also considering any other loads it must supply power to.
  :::

  In our gantry robot, the following values were set by default based on the motor article number:

  - **Brushless motors (X1, X2, Y)**: 7 A
  - **Stepper motor (Z)**: 3.2 A

- **Boost Current (A)**: Defines the maximum permissible current for the motor during acceleration and deceleration phases. During these periods, the maximum motor current set in the "Motor Current" parameter can temporarily increase up to the boost current value for a maximum duration of 2 seconds. Possible values range from the "Motor Current" parameter value up to 150 % (for stepper motors) or 300 % (for brushless motors) of the "Motor Current" parameter value.

  :::{important}
  As with the previous parameter, this value must be less than the maximum current the power supply can provide, taking into account any additional loads.
  :::

  In our gantry robot, the following values were set by default based on the motor article number:

  - **Brushless motors (X1, X2, Y)**: 21 A (300% of motor current)
  - **Stepper motor (Z)**: 3.2 A (100% of motor current)

- **Holding Current (A)**: Defines the current supplied to the motor when it is stopped. This setting is applicable only to open-loop stepper motors, otherwise the parameter will be disabled and grayed out.

  In our gantry robot, the controller was configured for closed-loop operation, so this option is disabled.

- **Step Mode**: This setting is applicable only to stepper motors, otherwise it will be disabled and grayed out. This parameter defines the microstepping technique to control the motor {cite}`electricmotorsanddrives,enwiki:1166298756`. Instead of moving the motor one full step at a time (1/1 step mode), microstepping divides each step into smaller fractions, enabling a greater number of intermediate positions. Available modes include "Auto," 1/1 (full step), 1/2, 1/4, 1/8, 1/16, 1/32, and 1/64.

  Smaller step sizes result in more precise positioning, improved movement stability, and reduced noise emission. However, the theoretical maximum speed will decrease. For example, a motor with a 1.8° step angle requires 200 steps to complete one revolution in 1/1 step mode. Generally, for a step angle $\theta$ and 1/N step mode, $360N/\theta$ steps are needed per revolution. Given that the controller can process step pulses with a minimum pulse period $T$, the theoretical maximum motor speed in RPM will be $60\theta/(360NT) = \theta/(6NT)$. Therefore, for a 1/N step mode, the theoretical maximum speed will be reduced by a factor of N compared to the theoretical maximum speed of the 1/1 mode.

  The igus® dryve D1 documentation specifies a minimum step pulse period of 40 μs. However, the actual minimum period is smaller. Using a signal generator and an oscilloscope, we have verified that the actual minimum step pulse period supported by the igus® dryve D1 is 4 μs. {numref}`tab:step_modes` shows the steps per revolution and theoretical maximum speeds in RPM for each step mode, considering a 1.8° step angle and a 4 μs minimum step pulse period. Note that the speeds presented in the table are theoretical values calculated from the formula $\theta/(6NT)$. In practice, stepper motors are not designed to reach high speeds. The maximum speed of a stepper motor depends on the motor model, but typically these motors do not exceed 1000 RPM.

  In our gantry robot setup, we have set the step mode to 1/32 for the Z axis stepper motor.

  :::{tabularcolumns} rrr
  :::

  :::{csv-table} Step modes, steps per revolution, and theoretical maximum speeds in rpm, considering a step angle of 1.8° and a minimum step pulse period of 4 µs.
  :class: align-col1-r, align-col2-r, align-col3-r
  :name: tab:step_modes
  :header: Step Mode, Steps per revolution, Maximum speed (rpm)
  :widths: auto

  1, 200, 75000
  1/2, 400, 37500
  1/4, 800, 18750
  1/8, 1600, 9370
  1/16, 3200, 4680
  1/32, 6400, 2340
  1/64, 12800, 1170
  :::

- **Step Angle**: This parameter, available only for stepper motors, defines the angle of a full motor step (e.g., 0.72°, 0.9°, 1.8°). It is a physical property of the motor itself and determines the number of full steps per revolution. For instance, a motor with a 1.8° step angle needs $360/1.8 = 200$ full steps per revolution.

  In our gantry robot, the stepper motor used has a step angle of 1.8°.

- **Pole Pairs**: This parameter, available only for brushless motors, defines the number and arrangement of the motor coils. It is a physical property of the motor itself.

  In our gantry robot, the brushless motors used have 4 pole pairs.

After completing the fields in this section, click the "Apply Changes" button.

## Gear

If the motor includes a reduction gear, it can be configured in this section.

In our gantry robot:

- **Brushless motors (X1, X2, Y)**: We have selected a gear with a ratio of 10:1
- **Stepper motor (Z)**: No gear is used

## Feedback

This section allows you to configure the parameters of the encoder connected to the controller. If an igus® motor was selected in the "Article Number" parameter within the "Motor" section, the parameters in this section will already be set to their correct values.

In our gantry robot setup, the following values were set by default based on the motor article number:

- **Brushless motors (X1, X2, Y)**
  - **Type**: Encoder as a Line Driver
  - **Index**: ON
  - **Impulses**: 1000
- **Stepper motor (Z)**
  - **Type**: Encoder as a Line Driver
  - **Index**: ON
  - **Impulses**: 500

:::{important}
The "Impulse Check" button prompts the controller to automatically verify the number of encoder impulses. To do this, it rotates the motor by one revolution, even if the "enable" signal is not activated. Therefore, do not click this button if the motor cannot rotate freely.
:::

## Closed Loop

Through closed-loop control, the controller continuously compares the position information received from the encoder with the desired reference value and adjusts the motor based on this comparison. This continuous feedback enables error correction, maintaining the motor's desired position, speed, or state, and more efficiently adapting to load variations. This results in precise and stable motor control, significantly reducing energy consumption and operating temperature.

We will set this option to "ON" for all motors in our gantry robot setup.

:::{important}
For closed-loop control, the igus® dryve D1 internally uses two {{PI}} controllers to control current and speed, respectively, and a {{P}} controller for position control. The parameters of these controllers are shown on the "Oscilloscope" page (see {numref}`sec:oscilloscope_parameters`). If the "Self Tuning" button in this section is pressed, the controller will attempt to automatically determine the optimal values for these parameters.
:::

## Brake

The igus® dryve D1 can control a holding brake. Since none of our motors are equipped with a brake, we will set this option to "OFF."

## Braking Resistor

This section applies only to brushless motors. When decelerating, these motors act as power generators. This can produce voltage peaks that exceed the applied load voltage, potentially damaging the controller, especially during rapid decelerations. To prevent damage, a braking resistor must be used to dissipate the excess energy generated. Therefore, it is essential that each controller driving a brushless motor is equipped with its own braking resistor.

Both the resistor's value and its power dissipation capacity depend on the specific motor used. The controller manual provides detailed information on the appropriate values depending on the motor used. For our gantry robot we used a 3.3 Ω resistor, with a maximum power dissipation capacity of 100 W using a standard heatsink.

This section provides a single parameter, "Braking Voltage (V)," which sets the voltage threshold at which the braking resistor engages to dissipate excess energy. For safe operation, the controller incorporates a hysteresis of 1 V; thus, the braking resistor will activate when the motor voltage reaches the threshold voltage plus 1 V, and will deactivate when it drops to the threshold voltage minus 1 V.

The voltage threshold set in the "Braking Voltage" parameter should be slightly higher than the motor's supply voltage. For instance, if the motor's supply voltage is 24 V, a suitable threshold could be 26 V. If the motor's supply voltage is 48 V, a suitable threshold could be 51 V. A value set too high could result in insufficient energy dissipation and trigger the "E09 Load Supply High" error (refer to the controller manual, Section 7: Alerts and Errors).

In our gantry robot setup, the brushless motors are powered at 48 V, so we set this parameter to 51 V.

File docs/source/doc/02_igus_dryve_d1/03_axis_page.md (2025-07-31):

(sec:page_axis)=

# "Axis" Page

The "Axis" configuration page is shown below in {numref}`fig:conf_x1_axis`. The parameters use the units established on the initial configuration page (see {numref}`sec:conf_start`); thus, position parameters are in millimeters (mm), speed parameters in millimeters per second (mm/s), and acceleration parameters in millimeters per second squared (mm/s{sup}`2`). The various options available on this page and their settings for our gantry robot configuration are described in the following sections.

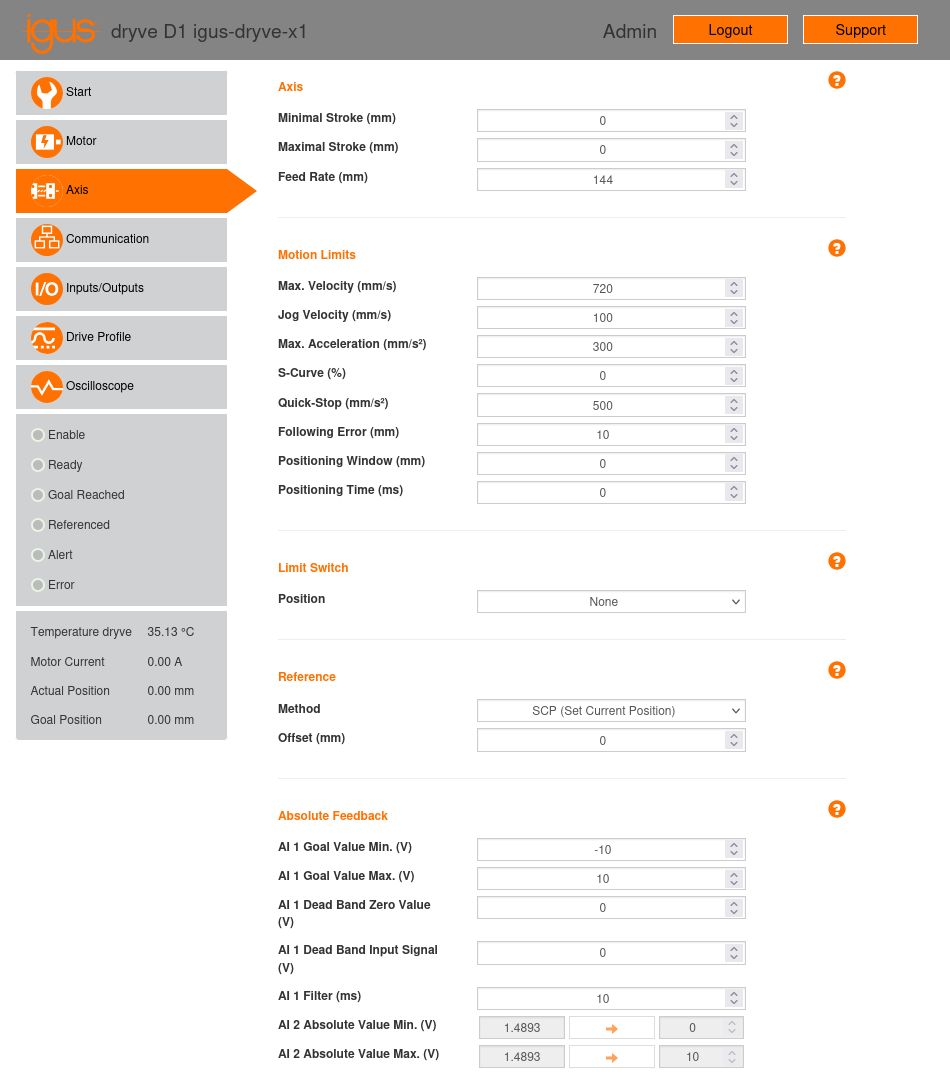
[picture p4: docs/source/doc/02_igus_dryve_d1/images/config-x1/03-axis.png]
:::{figure} images/config-x1/03-axis.png
:name: fig:conf_x1_axis

"Axis" configuration page of the X1 motor controller.
:::

## Axis Configuration Summary

{numref}`tab:axis_config_summary` below summarizes the configuration parameters for the axes:

:::{tabularcolumns} l\R{0.24}\R{0.24}
:::

:::{csv-table} Axis configuration summary for the gantry robot.
:name: tab:axis_config_summary
:widths: auto
:header: Parameter,Value (X1/X2/Y),Value (Z)
:class: longtable align-col2-r align-col3-r

**Axis**,,
Minimal Stroke (mm),0,0
Maximal Stroke (mm),0,0
Feed Rate (mm/s),144,4
**Motion Limits**,,
Max. Velocity (mm/s),720,50
Jog Velocity (mm/s),100,20
Max. Acceleration (mm/s{sup}`2`),300,3200
S-Curve (%),0,0
Quick-Stop (mm/s{sup}`2`),500,200
Following Error (mm),10,1
Positioning Window (mm),0,0
Positioning Time (ms),0,0
**Limit Switch**,,
Position,None,None
**Reference**,,
Method, SCP (Set Current Position), SCP (Set Current Position)
Offset (mm),0,0
**Absolute Feedback**,,
AI 1 Target Value Min. (V),-10,N/A
AI 1 Target Value Max. (V),10,N/A
AI 1 Dead Band Zero Value (V),0,N/A
AI 1 Dead Band Input Signal (V),0,N/A
AI 1 Filter (ms),10,N/A
AI 2 Absolute Value Min (V),N/A,N/A
AI 2 Absolute Value Max (V),N/A,N/A
:::

## Axis

This section contains the following parameters:

- **Minimal Stroke** and **Maximal Stroke**: These parameters specify the movement window for "ABS" mode (Absolute Positioning). Since we will not be using this mode, these parameters are not relevant to our application and they are both set to 0.

- **Feed Rate**: For linear axes, this parameter indicates the axis displacement per motor rotation. In our gantry robot setup the motors have the following feed rates:

  - **Brushless motors (X1, X2, Y)**: 144 mm/rev
  - **Stepper motor (Z)**: 4 mm/rev

(sec:axis_motion_limits)=

## Motion Limits

This section includes the following parameters:

- **Max. Velocity (mm/s)**: This sets the maximum motor speed. It functions as a limit for the movement programming modes available on the "Drive Profile" page (see {numref}`sec:page_drive_profile`). For the stepper motor (Z), speed will be controlled by the step signal received by the controller. For the brushless motors (X1, X2, Y), the maximum speed will be set on the "Drive Profile" page, with a value not exceeding that set here. In our gantry robot setup, we have configured the following values:

  - **Brushless motors (X1, X2, Y)**: 720 mm/s
  - **Stepper motor (Z)**: 50 mm/s

- **Jog Velocity (mm/s)**: This parameter defines the motor speed for manual positioning, accessible on the "Drive Profile" page (see {numref}`sec:page_drive_profile`). It is primarily useful for testing purposes via the controller's web interface. For the final system, this parameter is irrelevant.

- **Max. Acceleration (mm/s{sup}`2`)**: This sets the maximum motor acceleration, used in manual positioning on the "Drive Profile" page (see {numref}`sec:page_drive_profile`). It also serves as a limit in the movement programming modes available on the "Drive Profile" page. Similar to speed, for the stepper motor (Z), acceleration will be controlled by the step signal received by the controller. For the brushless motors (X1, X2, Y), the maximum acceleration will also be set on the "Drive Profile" page, with a value not exceeding that set here.
  
  :::{important}
  We have experimentally found that for the step/direction drive mode, the maximum acceleration also controls the jerk, i.e, the maximum rate of change of the acceleration over time, thus for the stepper motor (Z) we have set the maximum acceleration to a relatively high value.
  :::
  
  In our gantry robot setup, we have configured the following values:

  - **Brushless motors (X1, X2, Y)**: 300 mm/s{sup}`2`
  - **Stepper motor (Z)**: 3200 mm/s{sup}`2`

- **S-Curve (%)**: This parameter allows control over the rate of change of acceleration, known as "jerk" {cite}`enwiki:1178778094`. It can be adjusted between 0% and 100% to control the smoothness of acceleration and deceleration transitions in motor movement. Lower values will result in abrupt changes in acceleration, leading to higher "jerk" levels and, consequently, less smooth movements that can induce unwanted vibrations and stress on the system. Conversely, higher values will reduce "jerk," resulting in smoother acceleration and deceleration transitions, thereby minimizing vibrations and wear on both the motor and machinery.

  If an external controller (such as LinuxCNC) is to have full control over motor movement, this parameter should be set to 0%. In this configuration, any acceleration and deceleration smoothing within the motor controller itself is deactivated, allowing the external controller to directly manage the movement.

  However, LinuxCNC's current motion controller does not have a "jerk" limitation and uses constant acceleration. It might be desirable to set this parameter to a value greater than 0% to limit "jerk" and prevent unwanted vibrations and stress on the system. However, this approach would increase tracking error within LinuxCNC. Therefore, if this option is to be set above 0%, a balance between movement smoothness and tracking precision must be found.

  In our gantry robot setup, we have set the parameter to 0%.

- **Quick-Stop (mm/s{sup}`2`)**: This specifies the deceleration rate when a movement stops in an emergency. A quick stop is executed if the controller's "Enable" signal (digital input X2.7) is revoked.

  :::{important}
  It is important to ensure that the specified deceleration is appropriate for the intended application. A deceleration that is too low could result in an excessive stop time for the robot's movement; conversely, a deceleration that is too high could damage the robot's mechanical structure.
  :::

  In our gantry robot setup, we have configured the following values:

  - **Brushless motors (X1, X2, Y)**: 500 mm/s{sup}`2`
  - **Stepper motor (Z)**: 200 mm/s{sup}`2`

- **Following Error (mm)**: This defines the permissible deviation of the actual position from the desired position. A warning is issued if 50% of the allowed tracking error is reached. If the allowed tracking error is exceeded, the movement stops, and an error is reported.

  In our gantry robot setup, we have configured the following values:
  
  - **Brushless motors (X1, X2, Y)**: 10 mm
  - **Stepper motor (Z)**: 1 mm

- **Positioning Window (mm)**: This parameter defines a position range around a target point, extending in both positive and negative directions. For example, if the goal is to reach 100 mm and a positioning window of 10 mm is set, the system will consider the position to be within the target range if it falls anywhere between 90 mm and 110 mm. If the motor's actual position is within this window, the movement is considered complete, even if the motor is mechanically blocked. This prevents the system from continuously attempting to reach an exact position in case of an obstruction. If the positioning window is set to 0, this function is deactivated, and the system will not consider a range around the target point.

  In our gantry robot setup, we have set this parameter to 0, thereby deactivating this function.

- **Positioning Time (ms)**: This defines the duration, in milliseconds, for which the actual position must be maintained within the range defined by the positioning window before a movement is considered complete.

  In our gantry robot setup, we have set this parameter to 0.

(sec:limit_switch)=

## Limit Switch

This section includes a "Position" parameter that allows for specifying the position and number of limit sensors used.

In our gantry robot setup, the limit sensors are not connected to the controllers, they are only connected to the MESA 7I96S board, so limits are entirely managed by LinuxCNC. Therefore, we set the "Position" parameter to "None."

## Reference

This section allows for selecting the preferred referencing ("homing") method and position displacement ("offset").

Similar to robot movement limits (see {numref}`sec:limit_switch`), the "homing" process will also be fully controlled by LinuxCNC. Therefore, we have set the following parameters:

- **Method**: SCP (Set Current Position)
- **Offset (mm)**: 0

(sec:axis_absolute_feedback)=

## Absolute Feedback

The igus® dryve D1 controller has two analog inputs, AI 1 (Analog Input 1, input X4.1) and AI 2 (Analog Input 2, input X4.2). These are used to configure and control the target position or speed and the current position of the system, respectively. In our system, we will use analog input AI 1 to control the speed of the brushless motors (X1, X2, Y). Analog input AI 2 will not be used. For the stepper motor (Z), these inputs are not applicable, making this section relevant only for the brushless motors. Below are the parameters related to the analog inputs available in this section.

- **Parameters related to AI 1 (input X4.1)**:

  The AI 1 input will be used to control the speed of the brushless motors (X1, X2, Y) (see {numref}`sec:page_drive_profile`). The analog input control voltage will be ± 10 V, which must be configured on the "Inputs/Outputs" page (see {numref}`sec:page_input_outputs`). This voltage range must be considered when setting the AI 1 related parameters detailed below.

  - **AI 1 Target Value Min. (V)**: The minimum voltage value at analog input AI 1. We set its value to -10 V.
  - **AI 1 Target Value Max. (V)**: The maximum voltage value at analog input AI 1. We set its value to 10 V.
  - **AI 1 Dead Band Zero Value (V)**: This allows for setting a dead band symmetrically around 0 V in the target signal corresponding to analog input AI 1. This parameter can be specified in increments of 0.001 V. We set its value to 0 V.
  - **AI 1 Dead Band Input Signal (V)**: This allows for setting a dead band symmetrically around 0 V in the input signal of Analog Input AI 1. This parameter can be specified in increments of 0.001 V. We set its value to 0 V.
  - **AI 1 Filter (ms)**: This is the interval for averaging the signal. It is used to filter sudden signal variations and prevent inconsistencies in movement. Lower values result in a system that responds quickly but is more susceptible to noise or interference. Higher values result in a more stable system but with a longer response time. We set its value to 10 ms.

  The dead band parameters, "AI 1 Dead Band Zero Value" and "AI 1 Dead Band Input Signal," can be used to minimize unwanted motor movements during the idle state caused by increased ripple in the input signal or other interferences. Considering the above parameters, if the analog input voltage $x$ is already filtered as specified in the "AI 1 Filter" parameter, the target position or speed will be calculated using the following transfer functions:

  - $f_{\text{ZV}}(\cdot)$, corresponding to the "AI 1 Dead Band Zero Value" parameter and shown in {numref}`fig:deadband_zv`.
  - $f_{\text{IS}}(\cdot)$, corresponding to the "AI 1 Dead Band Input Signal" parameter and shown in {numref}`fig:deadband_is`.

  Thus, for the analog input value $x$, the target position or speed will be:

  $$y = (f_{\text{ZV}} \circ f_{\text{IS}})(x) = f_{\text{ZV}}(f_{\text{IS}}(x))$$

  :::{note}
  The calculation of the target position or speed is not explicitly stated in the controller manual (considering manual version 3.0.1) and has been determined experimentally. The manual only textually describes the "AI 1 Dead Band Zero Value" and "AI 1 Dead Band Input Signal" parameters, similar to the descriptions provided above.
  :::

:::{figure} images/f_zv/fig.*
:name: fig:deadband_zv

Transfer function $f_{\text{ZV}}(\cdot)$.
:::

:::{figure} images/f_is/fig.*
:name: fig:deadband_is

Transfer function $f_{\text{IS}}(\cdot)$.
:::

- **Parameters related to AI 2 (input X4.2)**:

  Analog input AI 2 is used to provide position information to the controller via an analog signal. In our case, we will not be using this input, so the parameters related to it are irrelevant.

  - **AI 2 Absolute Value Min (V)**: The minimum voltage value at analog input AI 2.
  - **AI 2 Absolute Value Max (V)**: The maximum voltage value at analog input AI 2.

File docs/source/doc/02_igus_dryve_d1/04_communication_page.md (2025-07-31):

(sec:page_communication)=

# "Communication" Page

The "Communication" configuration page, shown below in {numref}`fig:conf_x1_communication`, allows for the configuration of Ethernet and the controller's bus systems. The following sections describe the various options available on this page and their recommended settings for our gantry robot configuration.

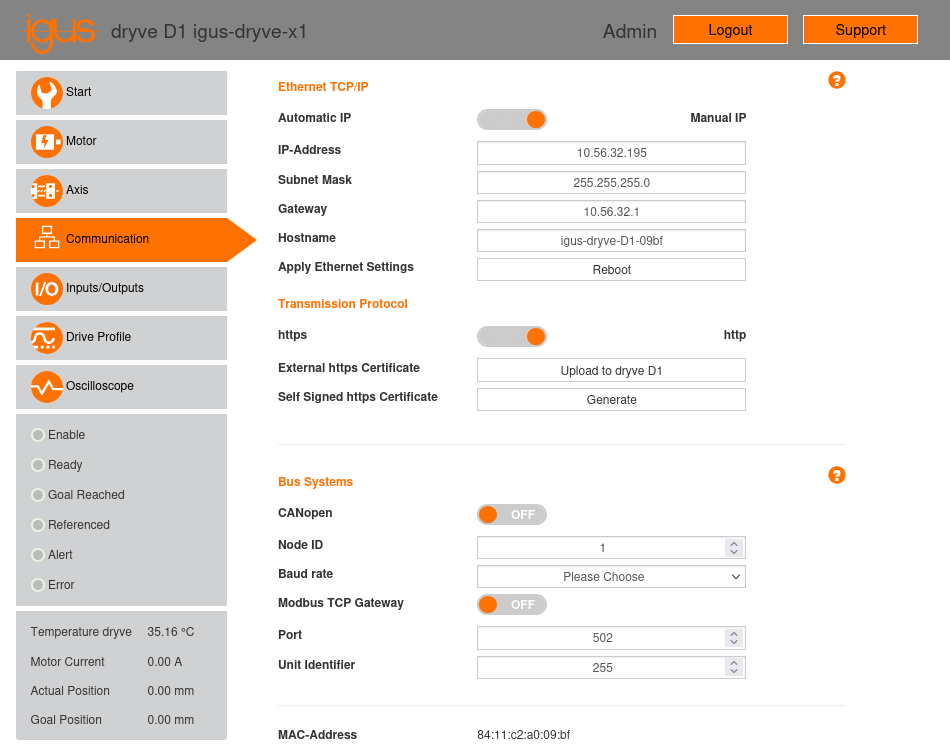
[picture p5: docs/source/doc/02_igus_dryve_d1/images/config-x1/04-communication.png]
:::{figure} images/config-x1/04-communication.png
:name: fig:conf_x1_communication

"Communication" configuration page of the X1 motor controller.
:::

## Ethernet TCP/IP

This section allows for configuring TCP/IP connection parameters: IP address, subnet mask, gateway, and hostname. After setting these parameters, you must click the "Reload" button to apply the changes.

In our gantry robot setup, these parameters were manually configured to the values shown below in {numref}`tab:conf_ethernet`. The controllers were connected to a PC via a switch. The parameters were configured to enable connectivity to the local network.

:::{csv-table} Ethernet configuration parameters for the gantry robot.
:name: tab:conf_ethernet
:widths: auto
:header: Parameter,Value (X1),Value (X2),Value (Y),Value (Z)

IP-Address,  10.56.32.195,       10.56.32.196,       10.56.32.197,      10.56.32.198
Subnet Mask, 255.255.255.0,      255.255.255.0,      255.255.255.0,      255.255.255.0
Gateway,     10.56.32.1,         10.56.32.1,         10.56.32.1,         10.56.32.1
Hostname,    igus-dryve-D1-09bf, igus-dryve-D1-098a, igus-dryve-D1-0979, igus-dryve-D1-09c3
:::

## Transmission Protocol

This section allows you to select whether communication with the dryve D1 controller's web server should be via an unencrypted HTTP connection or an encrypted HTTPS connection. For an HTTPS connection, an external certificate can be provided, or a self-signed certificate can be generated.

In our gantry robot setup, the option to use an unencrypted HTTP connection was selected.

## Bus Systems

The controller is equipped with two bus systems, CANopen and Modbus, which enable communication with the controller and control of motor movement. In our case, we will not use either of these systems, as we will control the motor using the inputs and outputs of connectors X2 (digital inputs), X3 (digital outputs), and X4 (analog inputs). Therefore, the "CANopen" and "Modbus TCP Gateway" options have been left at their default setting of "OFF."

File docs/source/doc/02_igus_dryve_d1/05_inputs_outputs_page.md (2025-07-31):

(sec:page_input_outputs)=

# "Inputs/Outputs" Page

The "Inputs/Outputs" configuration page, displayed below in {numref}`fig:conf_x1_inputs_outputs`, allows for configuring the controller's inputs and outputs.

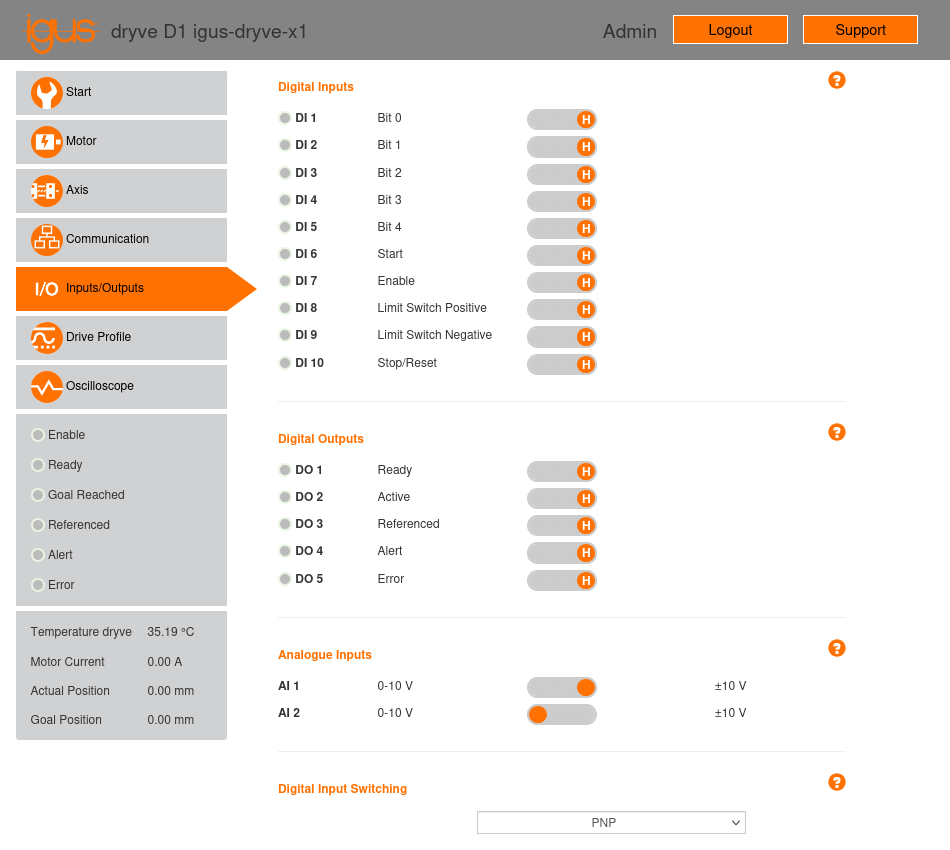
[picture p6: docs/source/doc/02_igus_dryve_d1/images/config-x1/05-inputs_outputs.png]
:::{figure} images/config-x1/05-inputs_outputs.png
:name: fig:conf_x1_inputs_outputs

"Inputs/Outputs" configuration page of the X1 motor controller.
:::

The digital logic level used by the controller is set by supplying input X2.11 with a voltage between 5 V and 24 V. The controller's digital logic operates as follows:

- Digital outputs are set to 0 V for a low level (L) and to the voltage of X2.11 for a high level (H).
- Digital inputs will be evaluated as a low level (L) for voltages between 0% and 10% of the X2.11 voltage, and as a high level (H) for values exceeding 60% of the X2.11 voltage.

These levels are illustrated in {numref}`fig:controller_logic_levels`.

:::{figure} images/logic_levels/fig.*
:name: fig:controller_logic_levels

Controller digital logic levels.
:::

To interact with the controller's digital inputs and outputs, we use the MESA 7I96S and 7I77 boards:

- The MESA 7I96S board transmits step and direction signals to the stepper motor controller; these signals operate on 5 V logic.
- The MESA 7I77 board sends "start" and "enable" signals, and reads the "ready," "alert," and "error" outputs from the controllers (refer to the wiring diagram in the {{project_url_link}}). The logic voltage for the MESA 7I77 board can be adjusted by supplying input TB2.1 ("field power") with the desired voltage, ranging from 5 V to 28 V.

Because the MESA 7I96S board can only use 5 V logic for step and direction signals, we have set the logic voltage for both the igus® dryve D1 controllers (X2.11 input) and the MESA 7I77 board (TB2.1 input) to 5 V.

The sections available on this page are:

- **Digital Inputs**: This section shows the digital inputs and allows you to select between normally open (H) or normally closed (L) for each. Normally open (H) inputs will activate upon receiving a high signal. Conversely, normally closed (L) inputs will activate upon receiving a low signal. We will keep all inputs set to their default value (H).

    :::{note}
    The labels for the digital inputs shown on this page will vary depending on the motor control mode selected on the "Drive Profile" page (see {numref}`sec:page_drive_profile`). {numref}`fig:conf_x1_inputs_outputs` shows the configuration for the X1 motor. For the Z motor, which is a stepper motor and uses the "step/direction" control mode, the inputs/outputs page will show the inputs for the "step" and "direction" signals.
    :::

- **Digital Outputs**: This section shows the digital outputs and allows you to select between normally open (H) or normally closed (L) for each. We will keep all outputs set to their default value (H).

- **Analog Inputs**: This section shows the analog inputs and allows you to set the supported value range from 0 V to 10 V or from -10 V to 10 V. In our case, we will use analog input AI 1 with -10 V to 10 V signals to control the speed of the brushless motors (X1, X2, Y), as mentioned in {numref}`sec:axis_absolute_feedback`. Therefore, on the brushless motor controllers, we will set the AI 1 option to ± 10 VDC. We will leave the AI 2 option unchanged, as we will not be using that input.

- **Digital Input Switching**: This parameter determines how the system interprets digital input signals. The available options are PNP and NPN:

  - **PNP** (sourcing): In the activated state, the input is raised to the voltage applied at X2.11. In the deactivated state, the input is grounded via a pull-down resistor. In this configuration, current flows from the output of the higher-level control system to the input of the igus® dryve D1.
  - **NPN** (sinking): In the activated state, the input is grounded. In the deactivated state, the input is raised to the voltage applied at X2.11 due to a pull-up resistor. In this configuration, current flows from the input of the igus® dryve D1 to the output of the higher-level control system.

    Since all inputs and outputs of the MESA boards are of the PNP (sourcing) type, we will leave this option set to the default value "PNP."

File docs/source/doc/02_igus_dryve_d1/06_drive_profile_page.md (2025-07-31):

(sec:page_drive_profile)=

# "Drive Profile" Page

This page allows you to select the control mode for executing movements. The available modes are:

- **Binary**: Movement control using digital or analog inputs and digital outputs.
- **Tipp/Teach**: Movement control using digital or analog inputs and digital outputs. In this mode, it is possible to modify the target positions of existing movements using digital inputs.
- **Step/Direction**: Movement control based on step and direction signals. This mode is only available for stepper motors.
- **CANopen**: Movement control via the CANopen communication protocol.
- **Modbus TCP**: Movement control via the Modbus TCP communication protocol.

Next, we will describe the configurations to apply to the motors in our gantry robot setup.

## Stepper motor (Z axis)

For the stepper motor, we select the "step/direction" control mode. {numref}`fig:conf_z_drive_profile` below shows the "Drive Profile" configuration page for the stepper motor controller when using the "step/direction" control mode. This control mode does not require any additional configuration; the page will simply show usage information for the step and direction signals.

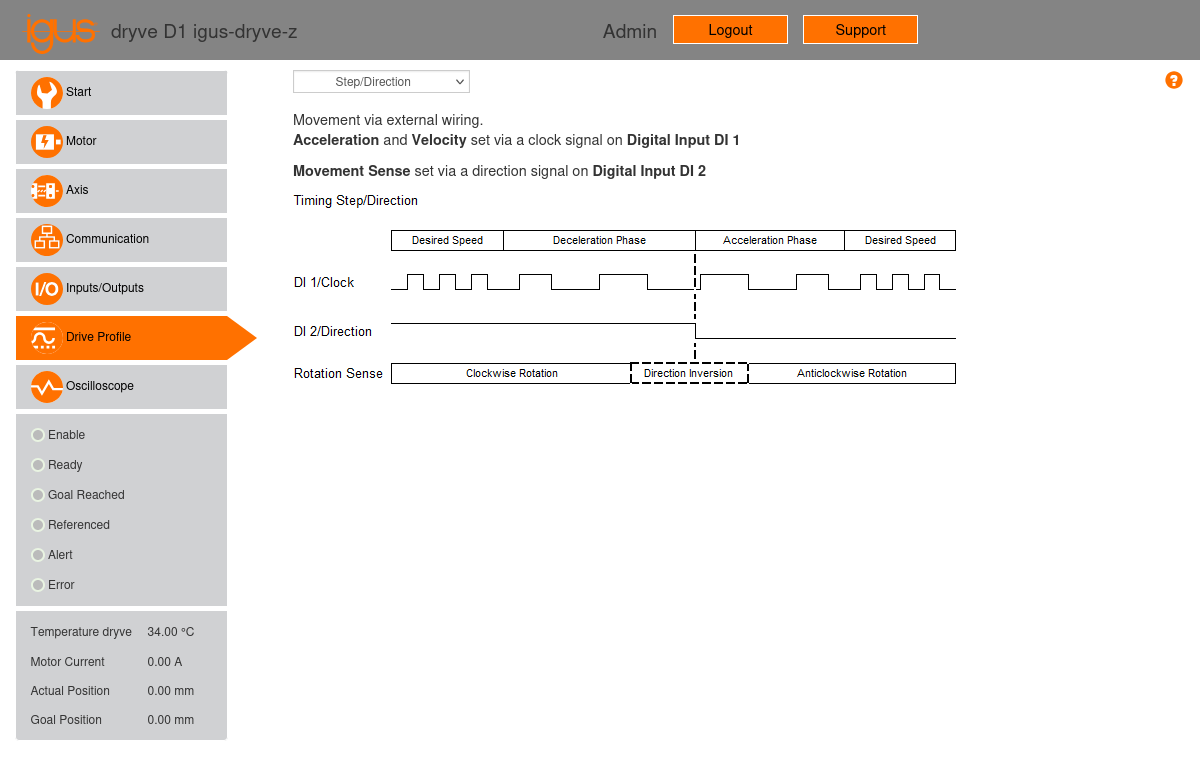
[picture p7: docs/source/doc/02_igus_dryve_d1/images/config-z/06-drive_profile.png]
:::{figure} images/config-z/06-drive_profile.png
:name: fig:conf_z_drive_profile

"Drive Profile" configuration page of the Z motor controller, using the "step/direction" control mode.
:::

## Brushless motors (X1, X2, Y axes)

For the brushless motors, we select the "binary" control mode. {numref}`fig:conf_x1_drive_profile` below shows the "Drive Profile" configuration page for the X1 motor controller, using the "binary" control mode. This mode provides a movement table (see {numref}`fig:conf_x1_drive_profile`) that allows for programming up to 32 parameterized movements, specifying the movement mode, target, maximum acceleration, speed, and the number of the next movement to execute. For the brushless motors, we will enter a single movement at position 1 using the ADR (Analogue Rotation with Direction Definition) mode. This mode enables rotary movements by setting their speed via the analog input AI 1.

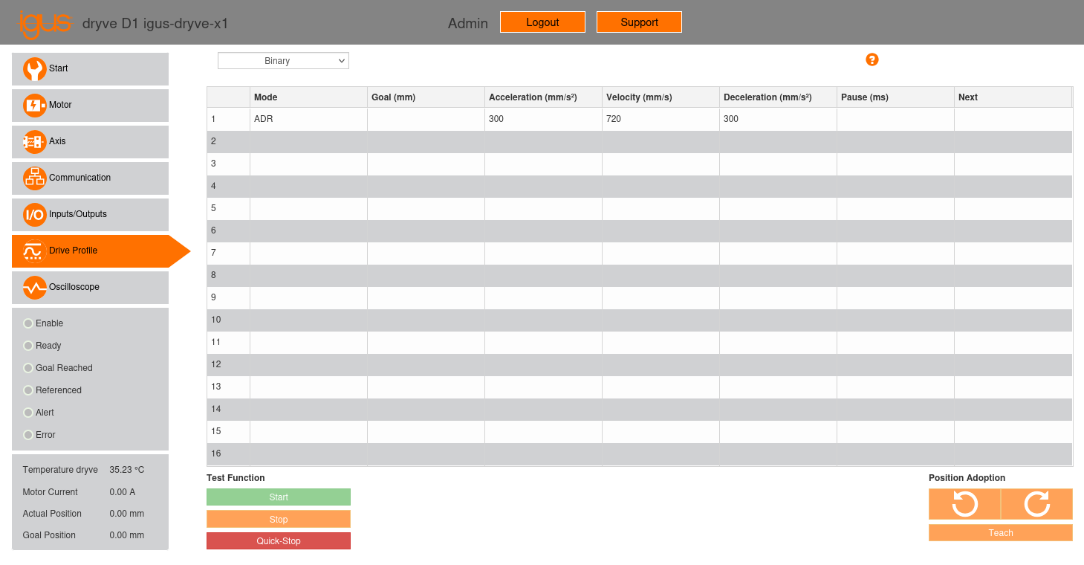
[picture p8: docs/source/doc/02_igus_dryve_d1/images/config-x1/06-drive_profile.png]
:::{figure} images/config-x1/06-drive_profile.png
:name: fig:conf_x1_drive_profile

"Drive Profile" configuration page of the X1 motor controller, using the "binary" control mode.
:::

In our gantry robot setup, we have configured the following parameters for the movement at position 1 for all brushless motors (X1, X2, Y):

- **Mode**: ADR (Analogue Rotation with Direction Definition).
- **Goal (mm)**: This field will be left empty.
- **Acceleration (mm/s{sup}`2`)**: 300 mm/s{sup}`2`.
- **Velocity (mm/s)**: 720 mm/s, equivalent to a motor speed of 3000 RPM.
- **Deceleration (mm/s{sup}`2`)**: 300 mm/s{sup}`2`, identical to the acceleration setting.
- **Pause (ms)**: This field will be left empty.
- **Next**: This field will be left empty.

:::{note}
As stated in {numref}`sec:hardware`, the X1, X2, and Y axes use linear units with a feed rate of 144 mm/rev and the motors have a 10:1 gear ratio. Therefore, an axis speed of 720 mm/s is equivalent to a motor speed of 720 × 60 × 10 / 144 = 3000 RPM.
:::

As explained in {numref}`sec:page_input_outputs`, analog input AI 1 was configured to operate within a range of ±10 V. The controller will vary the motor speed proportionally to the applied analog signal. Thus, when input AI 1 is set to -10 V, the motor will rotate at the maximum speed of 720 mm/s (3000 RPM) counter-clockwise, while when adjusted to 10 V, the motor will rotate at the maximum speed of 720 mm/s (3000 RPM) clockwise.

Once the movement is configured, it must be activated for the controller to move the motor. There are two activation methods:

1. Select the movement by clicking on row number 1 of the movement table and then clicking the "start" button at the bottom of the page.
2. Use the controller's digital inputs and outputs.

While option 1 may be suitable for testing, implementing option 2 is necessary for a production system. In this scenario, for a powered controller with the "enable" signal not yet activated, the following steps should be followed:

1. Set digital inputs 1 to 5 (X2.1 to X2.5) with the selected movement number minus one, where input 1 represents the least significant bit and input 5 the most significant. For example, for movement number 1, the inputs will be set to 00000; for 2, to 00001; and so on, up to 32, which will be set to 11111. For movement number 1, which is our case, digital inputs 1 to 5 can simply be left disconnected.
2. Set digital input 7 (X2.7, the "enable" input) to a high level.
3. Once the "enable" input is activated, wait for the controller to set digital output 1 (X3.1, the "ready" output) to a high level. This output indicates that the controller is prepared to accept position commands.
4. Once the "ready" output is activated, send a square pulse to digital input 6 (X2.6, the "start" signal) to initialize the movement program. The controller has a debounce filter with a time of 10 ms on digital inputs 1 to 10 (excluding step and direction inputs), so the pulse must have a duration greater than 10 ms for the controller to detect it. In our gantry robot setup, we have set the pulse duration to 100 ms.

In our gantry robot setup, the movement activation process has been configured in LinuxCNC and is executed using the MESA 7I77 board, which sends and receives the corresponding signals.

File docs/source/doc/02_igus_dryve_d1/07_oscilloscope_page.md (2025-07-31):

(sec:page_oscilloscope)=

# "Oscilloscope" Page

The "Oscilloscope" page, shown below in {numref}`fig:conf_x1_oscilloscope`, offers two essential functionalities for adjusting and monitoring motor performance: the internal oscilloscope and the configuration of the motor's closed-loop control parameters.

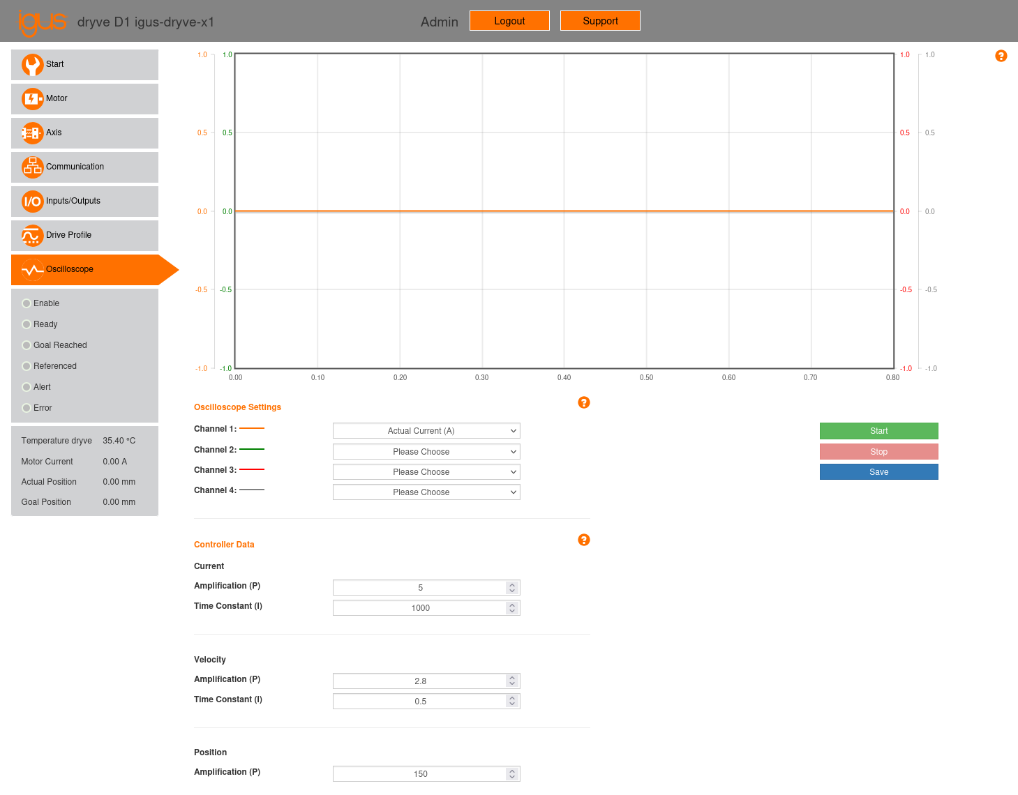
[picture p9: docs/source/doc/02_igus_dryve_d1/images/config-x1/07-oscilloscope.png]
:::{figure} images/config-x1/07-oscilloscope.png
:name: fig:conf_x1_oscilloscope

"Oscilloscope" configuration page of the X1 motor controller.
:::

## Oscilloscope

The oscilloscope allows for the simultaneous observation of four channels over a 5-second window, enabling a detailed evaluation of motor behavior in real time. Each channel can monitor one of the following values:

- Actual current (A)
- Tracking error
- Speed (RPM)
- Actual position
- Desired position
- Digital inputs
- Analog input 1 (AI 1)
- Analog input 2 (AI 2)

(sec:oscilloscope_parameters)=

## Control Parameters

:::{figure} images/motor_control/fig.*
:name: fig:motor_control

Closed-loop control of position, speed, and current.
:::

The igus® dryve D1 controller manual does not explicitly describe the control system it implements. We assume that it employs a closed-loop control system with "minor loop feedback compensation" {cite}`enwiki:1032838404,nise2015control,golnaraghi2017automatic`. In this system, the motor's position, speed, and current are used as feedback signals to precisely and dynamically adjust its position. This control system architecture is commonly used in motor control applications. Its structure, considering the {{P}} and {{I}} parameters defined by the igus® dryve D1 controller, is shown in {numref}`fig:motor_control`, where:

- $R(t)$ is the requested position for the motor at time $t$.

- $c(t)$ is the current supplied to the motor at time $t$, used as a feedback parameter for the current controller.

- $p(t)$ is the motor's position at time $t$, obtained from the motor's encoder and used as a feedback parameter for the position controller.

- $v(t)$ is the motor's speed at time $t$, obtained as the derivative with respect to $t$ of the position $p(t)$ and used as a feedback parameter for the speed controller.

- $e_c(t)$ is the current error, calculated as the output of the speed controller minus the current feedback parameter $c(t)$.

- $e_p(t)$ is the position error, calculated as $R(t) - p(t)$.

- $e_v(t)$ is the speed error, calculated as the output of the position controller minus the speed feedback parameter $v(t)$.

- $\kappa_p$ is the proportional parameter for the position controller.

- $\lambda_p$ and $\lambda_i$ are, respectively, the proportional and integral parameters for the speed controller.

- $\mu_p$ and $\mu_i$ are, respectively, the proportional and integral parameters for the current controller.

- $P(\alpha)(t)$ is the impulse response of the proportional block. For an input $x(t)$, the output of the proportional block at time $t$ is:

    $$x(t) * P(\alpha)(t) = \alpha \cdot x(t)$$

- $I(\beta)(t)$ is the impulse response of the integral block. For an input $x(t)$, the output of the integral block at time $t$ is:

    $$x(t) * I(\beta)(t) = \beta \int_{-\infty}^t x(\tau) d\tau$$

The "Oscilloscope" page provides access to the configuration of the {{PI}} controllers parameters. These parameters allow for optimizing motor performance to meet the specific requirements of each task. For igus® motors, by selecting the corresponding motor model in the motor configuration section (see {numref}`sec:motor_motor`), the control parameters will be set to the default values for the chosen motor. In applications involving high speeds, heavy loads, or when noise reduction is critical, fine adjustments to the control parameter configuration may be necessary.

{numref}`tab:oscilloscope_config_summary` below summarizes the configuration parameters for the oscilloscope in our gantry robot:

:::{tabularcolumns} lrr
:::

:::{csv-table} Oscilloscope configuration summary for the gantry robot.
:name: tab:oscilloscope_config_summary
:widths: auto
:header: Parameter,Value (X1/X2/Y),Value (Z)

**Current**,,
Amplification (P),5,15
Time constant (I),1000,8000
**Velocity**,,
Amplification (P),2.8,0.5
Time constant (I),0.5,24
**Position**,,
Amplification (P),150,100
:::

:::{note}
When configuring the motor control parameters in the "Oscilloscope" page, it is important to consider the following points:

- Parameters become effective upon pressing "enter" or unfocusing the corresponding parameter input field.
- Parameters require very fine adjustment; an abrupt change in a parameter can cause the corresponding {{PI}} controller to become unstable and result in sudden motor movement. In such a case, if the movement limit parameters have been adequately configured (see {numref}`sec:axis_motion_limits`), the controller should stop the motor and report a tracking error.
- Setting some parameters to excessively high values could lead to unwanted vibrations and noise in the motors due to oscillations in the {{PI}} controller signal. Conversely, setting some parameters to excessively low values could cause the motors to respond slowly to commands issued by the controller.
:::

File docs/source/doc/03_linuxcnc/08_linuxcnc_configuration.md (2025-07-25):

(sec:linuxcnc_configuration)=

# LinuxCNC Configuration

As noted in {numref}`sec:linuxcnc_intro_config`, a LinuxCNC configuration comprises several files, requiring at least one INI file and one {{HAL}} file. The following sections detail the configuration of both file types, using the `citic_gantry_robot` configuration as an example.

(sec:linuxcnc_configuration_ini)=

## INI Configuration

### .ini Configuration File Format

An `.ini` file is a plain text file used for configuring applications and programs. It has a simple structure consisting of sections and key-value pairs. The basic syntax of an `.ini` file is as follows:

- **Sections**: Sections serve to organize keys and values. Each section begins with its name enclosed in square brackets, followed by zero or more key-value pairs belonging to that section. The syntax for a section is:

  ```ini
  [section_name]
  ```

- **Keys and Values**: Within each section, keys and their corresponding values can be defined. Keys are identifiers used to access associated values. The syntax for a key-value pair is:

  ```ini
  key = value
  ```

  Keys can contain letters and underscores (`_`). Values can be text strings, integers, or floating-point numbers.

- **Comments**: Comments begin with a semicolon (`;`) or a hash symbol (`#`). For example:

  ```ini
  ; This is a comment
  # This is also a comment
  ```

(sec:linuxcnc_configuration_ini_file)=

### `citic_gantry_robot.ini` Configuration File

Below are the different sections of the `citic_gantry_robot.ini` configuration file, with comments explaining the purpose of each parameter.

:::{note}
Not all available parameters are specified in some sections. For a complete list of parameters and their documentation, consult the LinuxCNC user manual {cite}`linuxcncdoc`.
:::

:::{note}
Some parameters in INI files are used directly by LinuxCNC, but others are custom parameters added to be used in HAL files, as explained in {numref}`sec:linuxcnc_configuration_hal_format`. Parameters from the INI file can be accessed in HAL files using the syntax `[<section>]<option>`, where `[<section>]` is the section name in square brackets and `<option>` is the corresponding option name within that section.
:::

- **EMC Section**: General configuration.

  :::{literalinclude} codes/citic_gantry_robot.ini
  :language: ini
  :lines: 1-12
  :lineno-match:
  :::

- **DISPLAY Section**: User interface configuration. The available options may depend on the specific user interface used. In this case, we are using the AXIS user interface.

  :::{literalinclude} codes/citic_gantry_robot.ini
  :language: ini
  :lines: 14-71
  :lineno-match:
  :::

- **TASK Section**: LinuxCNC task controller configuration. The task controller is responsible for communicating with the user interface, the motion planner, and the G-code interpreter. Currently, `milltask` is the only task controller available. For more information, consult the LinuxCNC user manual {cite}`linuxcncdoc` and the `milltask` man page, also available at <http://linuxcnc.org/docs/devel/html/man/man1/milltask.1.html>.

  :::{literalinclude} codes/citic_gantry_robot.ini
  :language: ini
  :lines: 74-81
  :lineno-match:
  :::

- **RS274NGC Section**: RS274NGC (G-code) interpreter configuration.

  :::{literalinclude} codes/citic_gantry_robot.ini
  :language: ini
  :lines: 84-97
  :lineno-match:
  :::

- **EMCMOT Section**: Motion controller configuration. The `EMCMOT` and `SERVO_PERIOD` parameters are not directly used by LinuxCNC but are used to configure the motion control module in the {{HAL}} file (see {numref}`sec:linuxcnc_configuration_hal`).

  :::{literalinclude} codes/citic_gantry_robot.ini
  :language: ini
  :lines: 100-113
  :lineno-match:
  :::

- **{{HAL}} Section**: {{HAL}} configuration.

  :::{literalinclude} codes/citic_gantry_robot.ini
  :language: ini
  :lines: 116-130
  :lineno-match:
  :::

- **HALUI Section**: HALUI (HAL-based user interface) configuration. The only available option is `MDI_COMMAND`, which allows MDI commands to be executed via {{HAL}} signals. In our case we configure two commands which will be able to be executed via the PyVCP panel (see {numref}`sec:linuxcnc_configuration_pyvcp`).

  :::{literalinclude} codes/citic_gantry_robot.ini
  :language: ini
  :lines: 133-144
  :lineno-match:
  :::

- **KINS Section**: Kinematics configuration.

  :::{literalinclude} codes/citic_gantry_robot.ini
  :language: ini
  :lines: 147-155
  :lineno-match:
  :::

  For machines with Cartesian geometries, such as gantry robots, where the movement of a joint is directly proportional to the movement of the axis, LinuxCNC includes the `trivkins` kinematics module.

  The `trivkins` module accepts the `coordinates` parameter to specify the association of axis coordinate letters with the joint number. For example, with the parameter `coordinates=XZ`, `JOINT_0` will be assigned to `X` and `JOINT_1` to `Z`. In this parameter, the same axis letter can be specified multiple times, allowing multiple joints to be assigned to the same axis. In this case, it is also necessary to use the `kinstype=B` parameter. For instance, with the parameters `coordinates=XX` and `kinstype=B`, both `JOINT_0` and `JOINT_1` will be assigned to `X`.

  For our gantry robot system, we use the parameters `coordinates=XXYZ` and `kinstype=B`, which means that the axes-joints mapping is the following:

  - `X` axis → `JOINT_0` and `JOINT_1`
  - `Y` axis → `JOINT_2`
  - `Z` axis → `JOINT_3`

  For more information about the `trivkins` kinematics module, consult the `kins` man page, also available at <http://linuxcnc.org/docs/devel/html/man/man9/kins.9.html>.

- **APPLICATIONS Section**: LinuxCNC allows applications to be launched at startup. These applications must be specified within the `APPLICATIONS` section using the `APP` option, which can be used multiple times. Applications will be launched either at the beginning, before the graphical interface starts, or after a delay specified by the `DELAY` option.

  :::{literalinclude} codes/citic_gantry_robot.ini
  :language: ini
  :lines: 158-161
  :lineno-match:
  :::

- **TRAJ Section**: Trajectory planner configuration.

  :::{literalinclude} codes/citic_gantry_robot.ini
  :language: ini
  :lines: 164-181
  :lineno-match:
  :::

- **EMCIO Section**: Input/output controller configuration. This controls input/output tasks such as coolant, tool changes, and emergency stops.

  :::{literalinclude} codes/citic_gantry_robot.ini
  :language: ini
  :lines: 184-191
  :lineno-match:
  :::

- **AXIS\_\<i\> Section**: Configuration for axis *\<i\>*. Possible values for *\<i\>* include `X`, `Y`, `Z`, `A`, `B`, `C`, `U`, `V`, and `W`. Below we show the configuration for the X-axis. The configuration for the other axes is similar.

  :::{important}
  When configuring the robot's limits (`MIN_LIMIT` and `MAX_LIMIT` parameters), it is advisable to leave some margin beyond the desired workspace. If the robot is commanded to position itself at one of the limits, it can easily exceed that limit slightly. For example, if you want your robot to operate on the X-axis between X = 0 and X = 200, you could configure `MIN_LIMIT = -5` and `MAX_LIMIT = 205`.
  :::

  :::{literalinclude} codes/citic_gantry_robot.ini
  :language: ini
  :lines: 194-211
  :lineno-match:
  :::

- **JOINT\_\<n\> Section**: Configuration for joint (motor) *\<n\>*, where *\<n\>* is the joint number, ranging from 0 to (*\<num_joints\>* $-$ 1). The value of *\<num_joints\>* is set in the `JOINTS` option of the `KINS` section.

  :::{important}
  Both the joint and axis configurations include `MAX_VELOCITY`, `MAX_ACCELERATION`, `MIN_LIMIT`, and `MAX_LIMIT` parameters. When the robot is not homed, LinuxCNC uses the parameters from the joint sections, however, once the robot is homed, it uses the parameters from the axis sections.
  :::

  The following code shows the configuration of joint 0, which corresponds to the X1 brushless motor. The parameters specified below the comments starting with "Custom configuration:" are not directly used by LinuxCNC, they are used to configure the motor parameters in the {{HAL}} file (see {numref}`sec:linuxcnc_configuration_hal`).

  :::{literalinclude} codes/citic_gantry_robot.ini
  :language: ini
  :lines: 257-351
  :lineno-match:
  :::

  The following code shows the configuration of joint 3, which corresponds to the Z stepper motor. As before, the parameters specified below the comments starting with "Custom configuration:" are not directly used by LinuxCNC, they are used to configure the motor parameters in the {{HAL}} file (see {numref}`sec:linuxcnc_configuration_hal`). These parameters differ from the previous ones because now a stepper motor is used.

  :::{literalinclude} codes/citic_gantry_robot.ini
  :language: ini
  :lines: 546-663
  :lineno-match:
  :::

(sec:linuxcnc_configuration_hal)=

## {{HAL}} Configuration

{{HAL}} is a fundamental component of LinuxCNC, serving as an interface between the machine's software and hardware. It provides the infrastructure for communication among the system's numerous software and hardware components. The {{HAL}} layer is composed of components that:

- Are interconnected, processing incoming data and providing outputs to other components (e.g., the motion planning algorithm instructs the motors on their movement).
- Possess the ability to communicate with hardware.
- Always run periodically in one of the following ways:
  - As real-time components, either with an execution frequency of a few microseconds (e.g., to advance a stepper motor or read an encoder) or with a frequency less than one millisecond (e.g., to adjust the planning of subsequent movements to complete a G-code instruction).
  - As non-real-time user-space components, which can be interrupted or delayed if the rest of the system is busy or overloaded.

The {{HAL}} components included with LinuxCNC are listed in the user manual {cite}`linuxcncdoc`, also available at <http://linuxcnc.org/docs/stable/html/hal/components.html>. Additionally, each component has its own man page.

### Basic Concepts

- **Pins and Signals**: {{HAL}} is based on the same principles used to design electrical circuits and hardware systems, employing "pins" and "signals" to represent the flow of data between {{HAL}} modules or components. In summary:

  - Pins can carry boolean, float, and signed or unsigned integer values.
  - Pins have a direction: input (IN), output (OUT), or input/output (I/O).
  - A signal identifies a connection between pins.

  {numref}`fig:hal_circuit_concept` from the LinuxCNC documentation {cite}`linuxcncdoc` illustrates the concepts of components, pins, and signals in {{HAL}}. In the figure, pin `pin3-out` of `component.0` connects to pins `pin3-in` and `pin4-in` of `component.1` (via the `signal-red` signal), and pin `pin1-out` of `component.1` connects to pin `pin1-in` of `component.0` (via the `signal blue` signal).

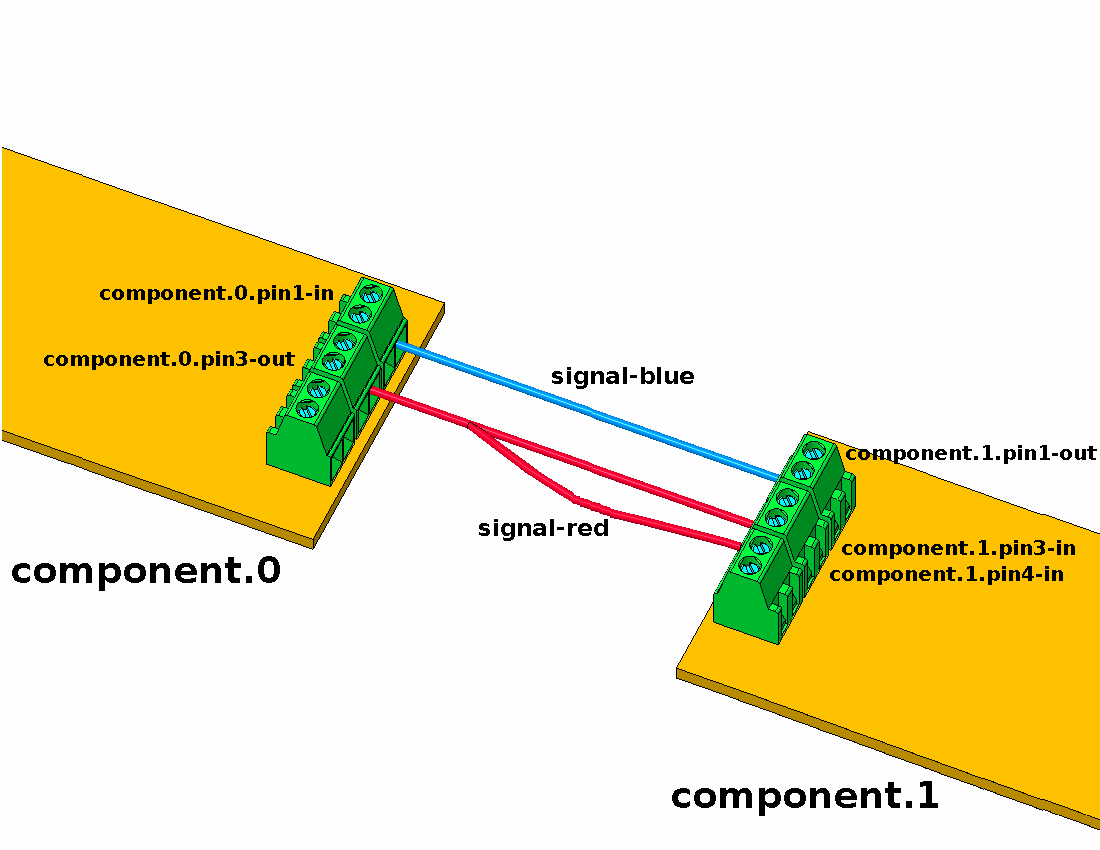
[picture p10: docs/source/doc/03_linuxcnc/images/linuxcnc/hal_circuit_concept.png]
  :::{figure} images/linuxcnc/hal_circuit_concept.png
  :name: fig:hal_circuit_concept

  {{HAL}} Concept --- Connection as electrical circuits. Source: LinuxCNC documentation {cite}`linuxcncdoc`.
  :::

- **Parameters**: {{HAL}} components can have parameters, which are input or output settings not connected to any other component. There are two types of parameters:

  - **Input parameters**: Values that the user can adjust and that remain fixed once configured.
  - **Output parameters**: Values that cannot be adjusted by the user. They allow for internal signals to be monitored.

- **Functions**: Each {{HAL}} component has one or more functions that must be executed to perform the component's task. For these functions to be executed, they must be added to a thread.

- **Threads**: Threads enable {{HAL}} component functions to be executed at specific time intervals. When a thread is created, the time interval at which its assigned functions will be executed is specified. Subsequently, the functions of the {{HAL}} components can be added to the thread to be executed in order at the thread's defined time interval.

### Interaction with {{HAL}} and Commands

{{HAL}} does not interact directly with the user. LinuxCNC provides various interfaces to configure or interact with {{HAL}}:

- From `.hal` files.
- From the command line using the `halcmd` command.
- From Python scripts.
- From C/C++ programs.

Configuration or interaction with {{HAL}} using any of these interfaces is performed through commands. The complete list of commands is detailed in the `halcmd` man page, also available at <http://linuxcnc.org/docs/html/man/man1/halcmd.1.html>. The most relevant commands are:

:::{note}
Generally, each command must be specified on a single line. If a command needs to be split across multiple lines, a backslash (`\`) character can be used to indicate that the line continues to the next. The backslash must be the last character before the new line.
:::

- `loadrt`: Loads a {{HAL}} real-time component into the system. The basic syntax of the `loadrt` command is:

  ```text
  loadrt <component> <options>
  ```

  where `<component>` is the name of the component and `<options>` are the component options. For example:

  ```hal
  loadrt mux4 count=1
  ```

- `addf`: Adds a function to a real-time thread. The syntax of the `addf` command is:

  ```text
  addf <function> <thread>
  ```

  where `<function>` is the name of the function and `<thread>` is the thread to which it will be added. For example:

  ```hal
  addf mux4.0 servo-thread
  ```

- `loadusr`: Loads a non-real-time {{HAL}} component into the system. Non-real-time components are separate processes that can optionally communicate with other {{HAL}} components via pins and parameters. Real-time components cannot be loaded into non-real-time space. The syntax of the `loadusr` command is:

  ```text
  loadusr [<flags>] <command>
  ```

  where `<command>` is the program command to be executed and `<flags>` can be one or more of the following options:

  - `-i`: Ignore the program's return value (with `-w`).
  - `-w`: Wait for the program to finish.
  - `-W`: Wait for the component to be ready. It is assumed that the component will have the same name as the first argument of the command.
  - `-Wn <name>`: Wait for the component to be ready and assign it the name `<name>`. This is only applicable if the component has the `-n` option to assign a name.

  For example:

  ```hal
  loadusr -Wn spindle gs2_vfd -n spindle
  ```

- `net`: Creates a connection between a signal and one or more pins. The syntax is as follows:

  ```text
  net <signal> <pin>
  ```

  where `<signal>` is the name of the signal and `<pin>` is the name of a pin. If the signal does not exist, a new signal is created. The command also allows the use of the words `<=`, `=>`, and `<=>`, separated by a space from the pin names, to indicate the direction of the signals between pins. These words are ignored by the command and merely serve to facilitate readability.

  The following rules must be met to connect a pin to a signal:

  - An input (IN) pin can always be connected to a signal.
  - An input/output (I/O) pin can be connected unless there is an output (OUT) pin on the signal.
  - An output (OUT) pin can be connected only if there are no other output (OUT) or input/output (I/O) pins on the signal.

  The same signal name can be used in multiple `net` commands to connect additional pins, provided the above rules are respected.

  Examples:

  - ```hal
     net home-x joint.0.home-sw-in <= parport.0.pin-11-in
     ```

     where `home-x` is the signal name, `joint.0.home-sw-in` is an input (IN) pin, `<=` is the optional direction arrow (ignored by the command), and `parport.0.pin-11-in` is an output (OUT) pin.

     This example can also be equivalently defined in {{HAL}} by two `net` commands:

     ```hal
     net home-x <= parport.0.pin-11-in
     net home-x => joint-0.home-sw-in
     ```

     :::{note}
     As seen in this example, although the second pin's name has the `-in` suffix, {{HAL}} treats it as an output pin. Therefore, when configuring pin connections in {{HAL}}, always refer to how the pin is configured in {{HAL}}, not just its name.
     :::

  - ```hal
    net xStep stepgen.0.out => parport.0.pin-02-out parport.0.pin-08-out
    ```

    where `xStep` is the signal name, `stepgen.0.out` is an output pin, and `parport.0.pin-02-out` and `parport.0.pin-08-out` are input pins.

    This example can also be defined in {{HAL}} by two `net` commands as follows:

    ```hal
    net xStep <= stepgen.0.out
    net xStep => parport.0.pin-02-out parport.0.pin-08-out
    ```

- `setp`: Sets the value of a pin or parameter. Valid values depend on the pin or parameter's data type. The syntax of this command is:

  ```text
  setp <name> <value>
  ```

  where `<name>` is the name of the pin or parameter and `<value>` is the value to which it is to be set. The command will fail if `<name>` does not exist as a pin or parameter, if it is a read-only parameter, if it is an output (OUT) pin, if it is a pin that is already connected to a signal, or if `<value>` is not a valid value for the pin or parameter's data type.

- `sets`: Sets the value of a signal. The syntax is:

  ```text
  sets <signal> <value>
  ```

  where `<signal>` is the name of the signal and `<value>` is the value to which it is to be set. The command will fail if `<signal>` does not exist as a signal, if the signal is already connected to an output (OUT) pin, or if `<value>` is not a valid value for the signal's data type.

- `unlinkp`: Unlinks a pin from its connected signal. The syntax of the command is:

  ```hal
  unlinkp <name>
  ```

    where `<name>` is the name of the pin. If the pin does not have a connected signal, nothing happens. The command will fail if `<name>` does not exist as a pin.

(sec:linuxcnc_configuration_hal_format)=

### .hal File Format

A `.hal` file is a plain text file containing {{HAL}} commands. Comments can be included by starting lines with the hash symbol (`#`). Options from the `.ini` file can be accessed with the syntax `[<section>]<option>`, where `[<section>]` is the section name in square brackets and `<option>` is the corresponding option name within that section.

### `citic_gantry_robot.hal` Configuration File

As noted in {numref}`sec:linuxcnc_intro_config`, a LinuxCNC configuration includes at least one `.ini` file and one `.hal` file. Below we show several fragments of the `citic_gantry_robot.hal` configuration file, the main {{HAL}} file for the `citic_gantry_robot.ini` file as detailed in {numref}`sec:linuxcnc_configuration_ini`. Unlike the `.ini` format, the `.hal` format does not have a section syntax, however, for clarity, the file is presented below divided into different parts.

:::{note}
The documentation of the different {{HAL}} components and its pins can be found in the LinuxCNC man pages {cite}`linuxcncdoc`. The components and pins available in the running system can be also explored using the `halcmd` or `halshow` tools. See {numref}`sec:linuxcnc_configuration_hal_tools` for more details.
:::

- **Load modules, add functions to threads, and other initial configurations**:

  :::{literalinclude} codes/citic_gantry_robot.hal
  :language: hal
  :lines: 1-139
  :lineno-match:
  :::

- **Brushless motor configuration:** The configuration for the brushless motor for the joint 0 (motor X1) is shown below. Configuration for the other brushless motors (joint 1 and joint 2) is similar.

  :::{literalinclude} codes/citic_gantry_robot.hal
  :language: hal
  :lines: 140-183
  :lineno-match:
  :::

- **Stepper motor configuration:** The configuration for the stepper motor for the joint 3 (motor Z1) is shown below.

  :::{literalinclude} codes/citic_gantry_robot.hal
  :language: hal
  :lines: 278-326
  :lineno-match:
  :::

- **Other configurations**: Configuration for other functions such as:
  - **Hazard light**: Turn on a safety light when the machine is in motion.
  - **Analog enable**: Enable the MESA 7I77 +- 10 V analog outputs.
  - **Step generator enable**: Enable the MESA 7I96S step / direction outputs.
  - **igus® Dryve enable inputs**: Set the enable signal to high for all igus® Dryve controllers.
  - **igus® Dryve status signals**: Read ready/alert/error states from all igus® Dryve controllers.
  - **Analog rotation program start**: Generate a oneshot pulse when the igus® Dryve controllers of brushless motors are ready to start the "ADR (Analogue Rotation with Direction Definition)" program of the motor controllers.
  - **External emergency stop**: Handle the external emergency stop input signal.
  - **Fault signal**: Set a fault signal to high if any controller signals an error or alert or the external emergency stop signal is activated.
  - **Emergency stop (ESTOP)**: Manage the fault / enable / reset signals.
  - **LED control via Classic Ladder**: Link classic ladder pins to the MESA 7I96S pins of the red/yellow/green LEDs. See {numref}`sec:linuxcnc_configuration_classic_ladder`.
  - **GUI disable buttons**: Set the disable signal of PyVCP buttons based on the machine state.
  - **Velocity signals**: Read velocity signals for all axes, to display the motor RPM in the PyVCP panel. See {numref}`sec:linuxcnc_configuration_pyvcp`.

  :::{literalinclude} codes/citic_gantry_robot.hal
  :language: hal
  :lines: 329-456
  :lineno-match:
  :::

(sec:linuxcnc_configuration_hal_tools)=

## {{HAL}} Tools

Several {{HAL}} tools are available for real-time visualization and diagnosis of pin states. The most notable ones are described below; for a complete list of tools, consult the LinuxCNC user manual {cite}`linuxcncdoc`.

### Halcmd

`halcmd` is a command-line tool for interacting with {{HAL}}. When `halcmd` is executed, the following command line will appear:

```text
halcmd:
```

This prompt allows you to enter and execute {{HAL}} commands. Besides the commands detailed previously in {numref}`sec:linuxcnc_configuration_hal`, other commands such as `show`, `list`, or `save` can be very useful. These commands enable printing various elements defined in {{HAL}}, such as pins, parameters, threads, etc. The complete list of commands is detailed in the `halcmd` man page, also available at <http://linuxcnc.org/docs/html/man/man1/halcmd.1.html>.

### Halshow

`halshow` is a graphical tool that allows viewing and monitoring {{HAL}} components such as pins, parameters, signals, and functions. This tool is shown in Figures {numref}`%s <fig:halshow_show>` and {numref}`%s <fig:halshow_watch>`. The tool has the following main elements:

- A tree view displaying {{HAL}} pins, parameters, signals, functions, etc. This view is located on the left side of the window, as seen in Figures {numref}`%s <fig:halshow_show>` and {numref}`%s <fig:halshow_watch>`.
- A text input field for executing {{HAL}} commands, located at the bottom, as shown in Figures {numref}`%s <fig:halshow_show>` and {numref}`%s <fig:halshow_watch>`.
- A "SHOW" tab where information about the selected element in the tree view is displayed, as shown in {numref}`fig:halshow_show`.
- A "WATCH" tab where you can monitor and set values of {{HAL}} pins or parameters. Elements can be added here by clicking on them in the tree view, as shown in {numref}`fig:halshow_watch`.
- A "SETTINGS" tab with various options such as refresh interval or display format of parameters.

The {menuselection}`File` menu allows saving monitored elements from the "WATCH" tab to a file, as well as loading an existing list of elements to monitor from a file.

You can open the Halshow tool from the AXIS graphical interface by clicking on {menuselection}`Machine --> Show Hal Configuration`.

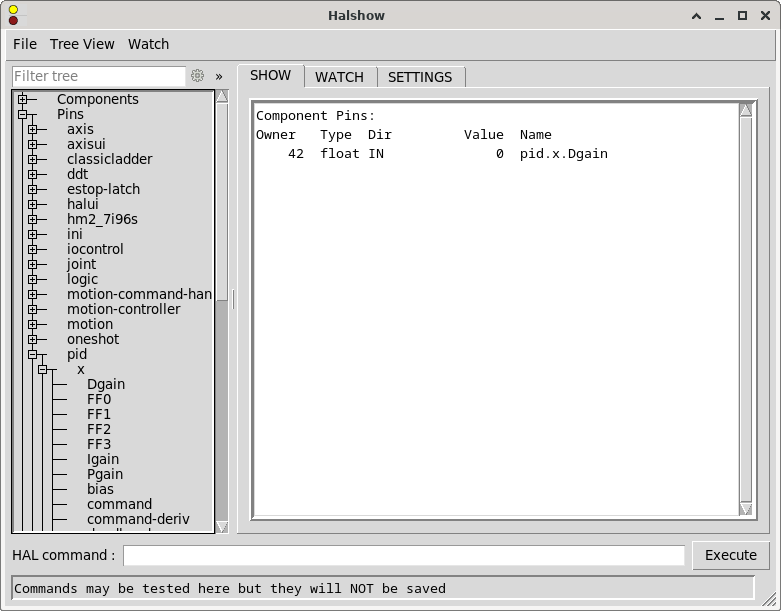
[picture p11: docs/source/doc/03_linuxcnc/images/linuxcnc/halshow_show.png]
:::{figure} images/linuxcnc/halshow_show.png
:name: fig:halshow_show
:width: 90%

Halshow tool showing the "SHOW" tab.
:::

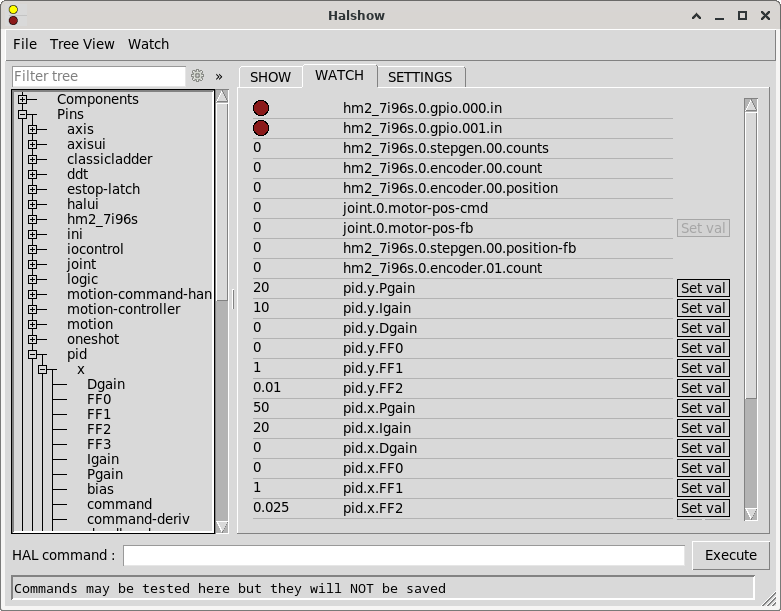
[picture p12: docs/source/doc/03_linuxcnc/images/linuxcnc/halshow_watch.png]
:::{figure} images/linuxcnc/halshow_watch.png
:name: fig:halshow_watch
:width: 90%

Halshow tool showing the "WATCH" tab.
:::

### Halscope

`halscope` is a graphical tool that provides an oscilloscope for {{HAL}}. It allows capturing and displaying the values of pins, signals, and parameters over a period of time. This tool is shown in {numref}`fig:halscope`. The {menuselection}`File` menu allows saving the current configuration or opening a previously saved configuration. When `halscope` is closed, the configuration is automatically saved to the `autosave.halscope` file.

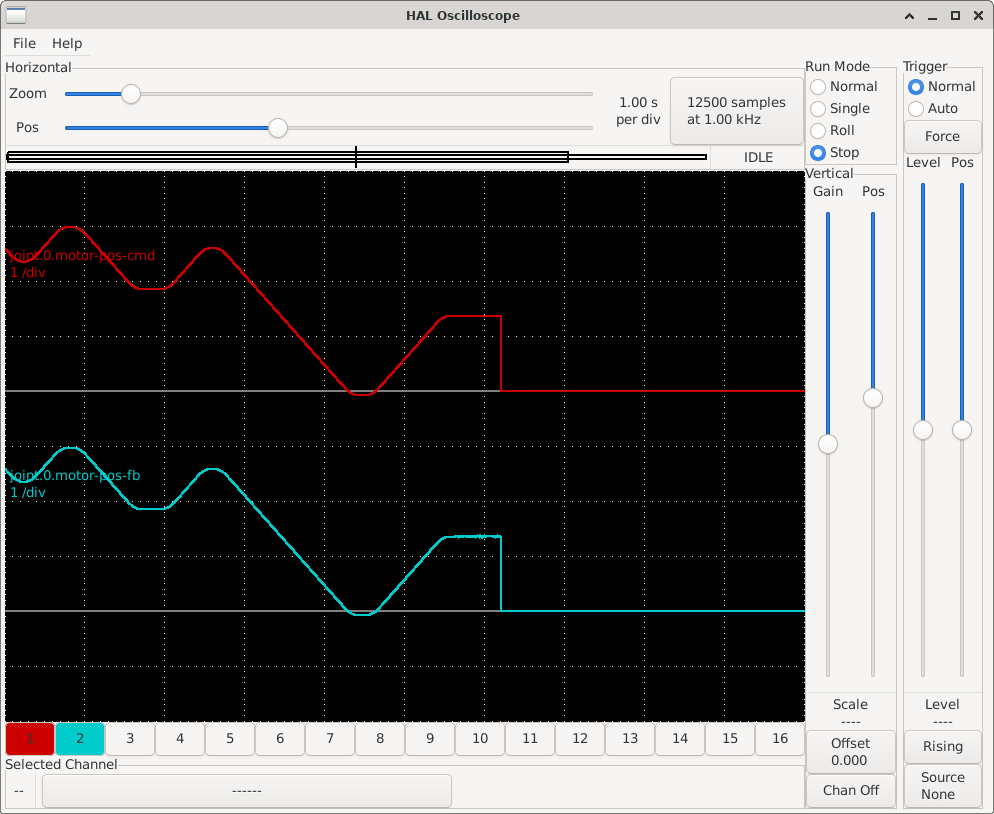
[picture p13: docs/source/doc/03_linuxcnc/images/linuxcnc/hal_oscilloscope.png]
:::{figure} images/linuxcnc/hal_oscilloscope.png
:name: fig:halscope

Halscope tool showing the values of `joint.0.motor-pos-cmd` (motor position commanded by LinuxCNC) and `joint.0.motor-pos-fb` (motor position read from the encoder) over time.
:::

You can open the Halscope tool from the AXIS graphical interface by clicking on {menuselection}`Machine --> Hal scope`.

### Halreport

`halreport` is a command-line tool that generates a report on {{HAL}} connections. The command's help output is as follows:

```text
Usage:
    halreport -h | --help (this help)
or
    halreport [outfilename]
```

The generated report displays all signal connections and indicates potential issues. The information included in the report, among other things, is:

- System description and kernel version.
- Signals and their connected output, input, and input/output pins.
- Functions, threads, and `addf` commands corresponding to each pin.
- Real names for pins that use aliases.
- Signals without an output.
- Signals without inputs.
- Functions not added to threads.
- Warnings about components marked as obsolete.

(sec:linuxcnc_configuration_pyvcp)=

## PyVCP (Python Virtual Control Panel)

PyVCP (Python Virtual Control Panel) is a LinuxCNC component that allows creating custom graphical user interface panels to complement the main LinuxCNC interface. These panels can be used to provide additional controls, indicators, and displays that can be tailored to specific machine requirements. The PyVCP GUI components can be connected to {{HAL}} pins for real-time interaction with the machine. Some of the PyVCP components are:

- **LED indicators**: Visual status indicators that can show the state of a {{HAL}} pin.
- **Buttons**: Interactive controls that can set the value of a {{HAL}} pin.
- **Bar displays**: Graphical representations of float {{HAL}} pins.
- **Labels**: Text displays for showing information.
- **Tables**: Layout containers for organizing components in rows and columns.

For the complete list of components and their configuration options, consult the PyVCP section of the LinuxCNC user manual {cite}`linuxcncdoc` (<https://linuxcnc.org/docs/html/gui/pyvcp.html>).

For our gantry robot system, we configured a PyVCP panel with LED status indicators, motor RPM displays, motor controller status indicators, and some convenient control buttons. {numref}`fig:linuxcnc_gui_pyvcp` shows the LinuxCNC AXIS interface with the custom PyVCP panel integrated on the right side.

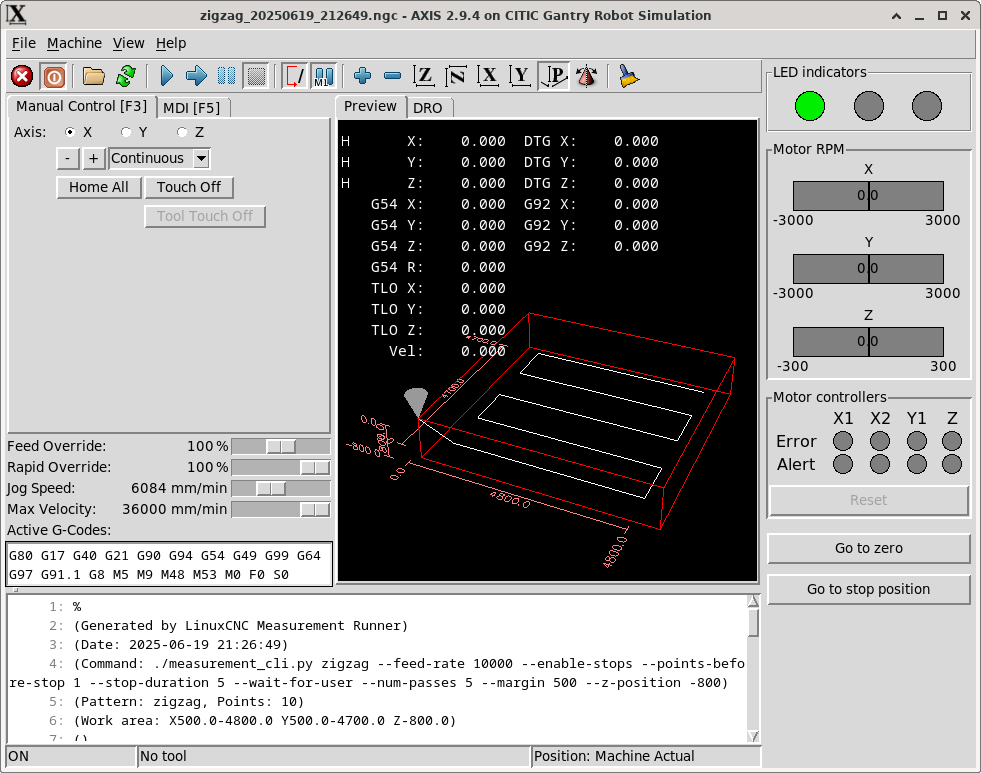
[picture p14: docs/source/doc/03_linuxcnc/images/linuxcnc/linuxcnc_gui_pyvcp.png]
:::{figure} images/linuxcnc/linuxcnc_gui_pyvcp.png
:name: fig:linuxcnc_gui_pyvcp

LinuxCNC AXIS interface showing the custom PyVCP panel with LED indicators, motor RPM displays, controller status, and control buttons.
:::

### PyVCP Configuration

PyVCP is configured in the `DISPLAY` section of the INI file using the `PYVCP` parameter:

```ini
PYVCP = gui_panel.xml
```

This parameter specifies the XML file that defines the panel layout and components. The XML file must be located in the same directory as the configuration files.

By default the panel appears at the right of the AXIS user interface. The panel can be also configured to appear at the bottom of the AXIS user interface by specifying the following in the [DISPLAY] section of the INI file:

```ini
PYVCP_POSITION = BOTTOM
```

### `gui_panel.xml` Configuration File

The gantry robot configuration uses a PyVCP panel that provides some monitoring and control capabilities. The panel is defined in the `gui_panel.xml` file and includes several functional sections. Below are the different sections of the `gui_panel.xml` configuration file.

**LED Indicators**: Displays the main system status with three colored LEDs.

:::{literalinclude} codes/gui_panel.xml
:language: xml
:lines: 4-35
:lineno-match:
:::

**Motor RPM**: Shows real-time motor RPM speeds using bar displays:

:::{literalinclude} codes/gui_panel.xml
:language: xml
:lines: 40-67
:lineno-match:
:::

**Motor Controllers**: Displays error and alert status for each motor controller, and allows sending a reset signal to the motor controllers.

:::{literalinclude} codes/gui_panel.xml
:language: xml
:lines: 72-165
:lineno-match:
:::

**Control Buttons**: Provides convenient buttons for common operations:

:::{literalinclude} codes/gui_panel.xml
:language: xml
:lines: 170-183
:lineno-match:
:::

### PyVCP Integration with {{HAL}}

Each PyVCP component that needs to interact with the machine creates a corresponding {{HAL}} pin. These pins can be connected to other {{HAL}} components in a `.hal` configuration file to provide the desired functionality. This file has to be specified in the `POSTGUI_HALFILE` parameter of the `HAL` section of the INI file.

Examples of PyVCP components and the corresponding {{HAL}} pins are:

- LED components create input pins (e.g., `pyvcp.led-green`, `pyvcp.led-red`)
- Button components create output pins (e.g., `pyvcp.gui-goto-zero-position-button`). Additionally, when the `disable_pin` parameter is set to `true`, a `disabled` pin is created (e.g., `pyvcp.gui-goto-zero-position-button.disabled`).
- Bar displays create input pins for displaying values (e.g., `pyvcp.x-rpm`, `pyvcp.y-rpm`)

In our case, the corresponding PyVCP panel `.hal` file is `gui_panel.hal`.

### `gui_panel.hal` Configuration File

The `.hal` file for our PyVCP panel is `gui_panel.hal` and is specified in the `POSTGUI_HALFILE` parameter of the `HAL` section of the INI file as shown in {numref}`sec:linuxcnc_configuration_ini_file`. This file is used to connect the PyVCP components to the {{HAL}} pins. The file is shown below.

:::{literalinclude} codes/gui_panel.hal
:language: hal
:lineno-match:
:::

(sec:linuxcnc_configuration_classic_ladder)=
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

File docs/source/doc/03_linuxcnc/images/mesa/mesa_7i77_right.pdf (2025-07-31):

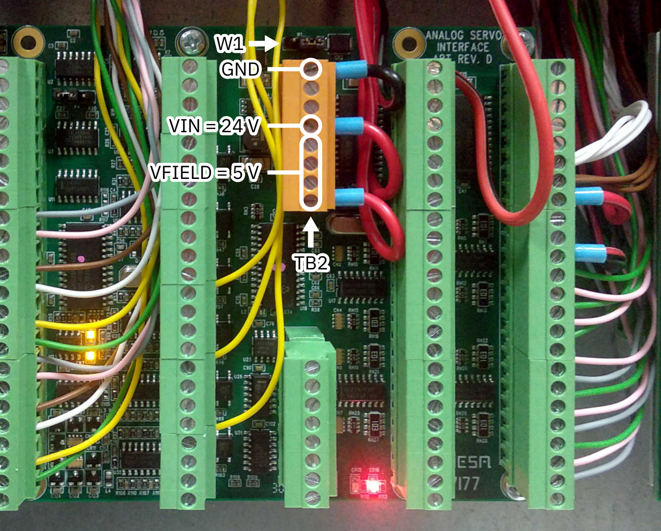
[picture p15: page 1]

W1

TB2

GND

VIN = 24 V

VFIELD = 5 V

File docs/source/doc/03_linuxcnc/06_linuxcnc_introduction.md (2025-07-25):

# Introduction to LinuxCNC

LinuxCNC is a highly customizable suite of applications for controlling {{CNC}} machines, 3D printers, robots, and other automated devices. It is capable of providing coordinated control of up to nine axes of motion. LinuxCNC comprises several key components integrated into a complete system {cite}`linuxcncdoc`:

- A {{GUI}}, which serves as the primary interface between the operator, the software, and the {{CNC}} machine itself.
- The {{HAL}}, which enables the linking of signals from the external environment with LinuxCNC and vice versa.
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

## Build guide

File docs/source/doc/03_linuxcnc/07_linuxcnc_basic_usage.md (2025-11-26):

---
myst:
  substitutions:
    button_estop: "button_estop"
    button_on_disabled: "button_on_disabled"
    button_on: "button_on"
    button_run: "button_run"
    homed_symbol: "homed_symbol"
---

(sec:linuxcnc_usage)=

# Basic LinuxCNC Usage

During the development of the gantry robot system, we created several LinuxCNC configurations:

- Configurations for single-axis movement:
  - `citic_gantry_robot_xx`: Configuration for moving the robot along the X-axis.
  - `citic_gantry_robot_xx_no_homing`: Configuration for moving the robot along the X-axis without the need for executing the physical homing procedure.
  - `citic_gantry_robot_y`: Configuration for moving the robot along the Y-axis.
  - `citic_gantry_robot_z`: Configuration for moving the robot along the Z-axis.
- Configurations for 3-axis movement:
  - `citic_gantry_robot`: Main configuration for the gantry robot system.
  - `citic_gantry_robot_sim`: Simulation configuration for the gantry robot system. Can be used to test the robot system configuration without the physical hardware.

The following sections explain the basic usage of LinuxCNC with these configurations.

(sec:linuxcnc_usage_gui_axis)=

## Control using the AXIS Graphical Interface

When LinuxCNC is launched with one of the aforementioned configurations, the AXIS graphical interface will open, as shown in {numref}`fig:linuxcnc_gui_axis_estop`. The process for controlling the machine with this interface is detailed below.

### Setting LinuxCNC to the "ON" State

The initial state of LinuxCNC will be "ESTOP" (emergency stop), indicated at the bottom left of the window, thus disabling robot movement. To start the robot, you must first clear the "ESTOP" condition. To do this, proceed as follows:

1. Deactivate the physical emergency stop switch (see {numref}`fig:installation`). If this switch is active, it forces the emergency stop state in LinuxCNC.
2. Deactivate the emergency stop state in LinuxCNC by pressing the {{button_estop}} button.

Once the emergency stop state is deactivated, LinuxCNC will transition to the "OFF" state, and the start button will change from a deactivated state ({{button_on_disabled}}) to an activated state ({{button_on}}).
To begin using the robot, press this button, which will transition LinuxCNC to the "ON" state. {numref}`fig:linuxcnc_gui_axis_on` shows the AXIS interface in the "ON" state.

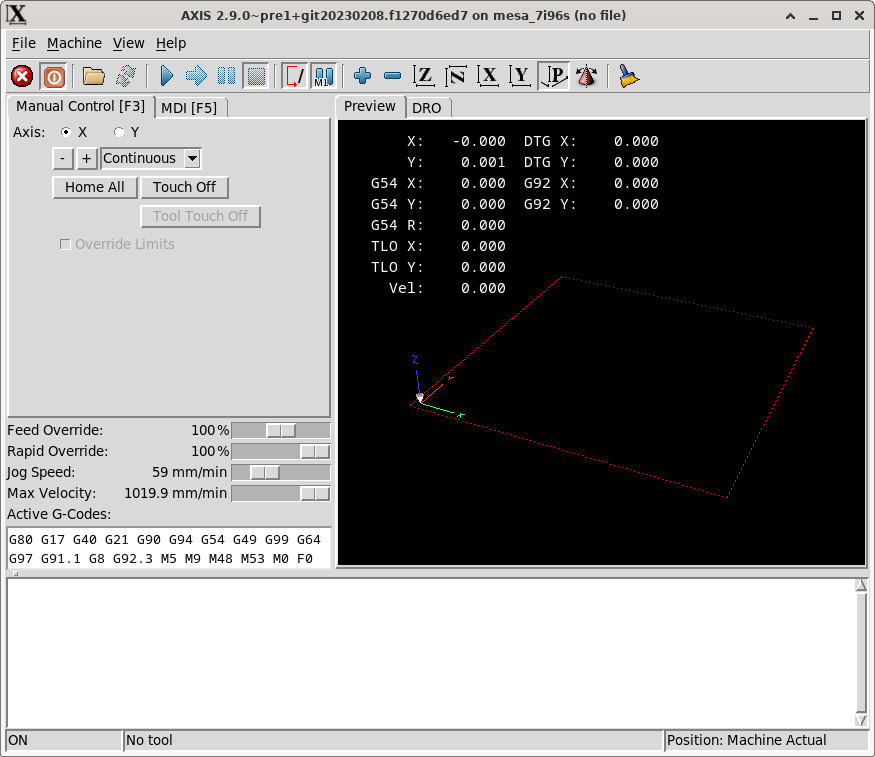
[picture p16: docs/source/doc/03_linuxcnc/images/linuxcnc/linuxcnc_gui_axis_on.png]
:::{figure} images/linuxcnc/linuxcnc_gui_axis_on.png
:name: fig:linuxcnc_gui_axis_on

LinuxCNC "AXIS" graphical interface in "ON" state.
:::

### Homing the Machine

Once LinuxCNC is in the "ON" state, you can manually control the machine using the {guilabel}`-` and {guilabel}`+` controls on the "Manual Control" tab. However, to execute specific G-code positioning commands (e.g., moving the machine to X=1, Y=5), it is necessary to perform the homing process. The homing procedure involves establishing a precise reference point for all machine axes, providing LinuxCNC with exact knowledge of the machine's current position.

To perform the homing process, you can click the {guilabel}`Home All` button on the "Manual Control" tab or select the menu entry {menuselection}`Machine --> Homing --> Home all axes`. In the gantry robot system, the homing process uses a single limit switch per motor. The procedure LinuxCNC follows for homing with limit switches is as follows:

1. Move the motor towards the limit switch until it is activated.
2. Move the motor in the opposite direction until the limit switch is deactivated.
3. Move the motor again towards the limit switch until it is activated, this time at a slower speed to precisely locate the switch's position.
4. Move the motor to the designated home reference position.

{numref}`fig:linuxcnc_gui_axis_on_homed` shows the interface window after the homing process is complete. The {{homed_symbol}} symbol can now be seen next to the X and Y axis information in the display area, indicating that the axes are homed.

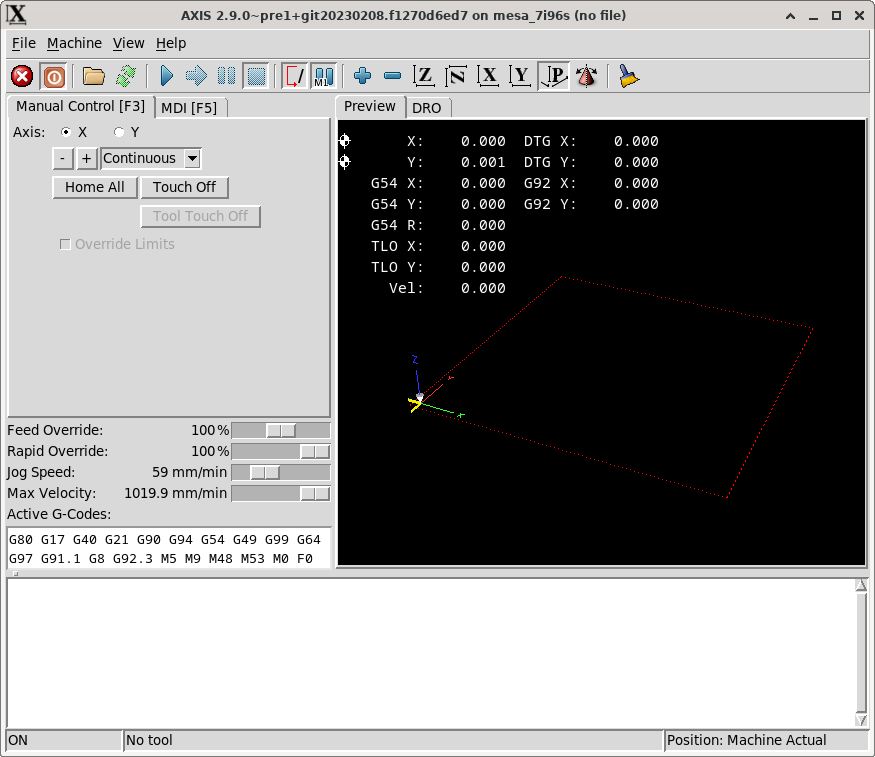
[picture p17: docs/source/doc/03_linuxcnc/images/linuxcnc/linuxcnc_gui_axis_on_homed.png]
:::{figure} images/linuxcnc/linuxcnc_gui_axis_on_homed.png
:name: fig:linuxcnc_gui_axis_on_homed

LinuxCNC "AXIS" graphical interface in "ON" state with all axes homed.
:::

### Controlling the Machine

As mentioned in {numref}`sec:linuxcnc_modes_of_operation`, LinuxCNC offers three control modes: manual, MDI, and automatic. The AXIS interface allows controlling the machine using these modes as follows:

- **Manual mode**: You can control the machine manually via the {guilabel}`-` and {guilabel}`+` controls on the "Manual Control" tab.
- **MDI mode**: You can use MDI mode via the "MDI" tab, where G-code commands can be entered line by line.
- **Automatic mode**: You can load a G-code program from a file by clicking on {menuselection}`File --> Open` and then execute it in automatic mode by clicking the {{button_run}} button or pressing the {kbd}`R` key.

For more information on G-code control, consult the "G-code programming" section in the LinuxCNC manual {cite}`linuxcncdoc`.

## Programmatic Control

LinuxCNC can be controlled programmatically by including a sequence of instructions in two ways:

1. Using G-code programs stored in a file, as mentioned in the previous section.
2. Using Python programs with the `linuxcnc` library, which is included with LinuxCNC and allows interaction with the running LinuxCNC process. For more information, consult the "Python Interface" section in the LinuxCNC user manual. {numref}`lst:linuxcnc_python` provides an example of robot control using Python by sending G-code commands in MDI mode.

```{code-block} python
:name: lst:linuxcnc_python
:caption: Example of using Python to interact with LinuxCNC

#!/usr/bin/env python3
# Example of LinuxCNC control with Python
# See the LinucCNC user manual, section 13.5 - Python Interface

import sys
import linuxcnc

def control_robot(c: linuxcnc.command) -> None:
    def set_feed_rate(v: float):
        # set robot feed rate
        c.mdi(f"F{v}")
        c.wait_complete()

    def go_to(x: float, y: float):
        # go to position (x, y)
        print(f"Going to ({x}, {y})...", end="", flush=True)
        c.mdi(f"G1 X{x} Y{y}")
        while (ret := c.wait_complete(1)) == -1:
            continue
        print(" done")
        if ret == linuxcnc.RCS_ERROR:
            print("RCS_ERROR")

    # Put your robot commands here
    set_feed_rate(400)
    go_to(0, 0)

def main():
    s = linuxcnc.stat()  # connect to the status channel
    c = linuxcnc.command()  # connect to the command channel

    def ok_for_mdi() -> bool:
        s.poll()
        return (
            not s.estop
            and s.enabled
            and (s.homed.count(1) == s.joints)
            and (s.interp_state == linuxcnc.INTERP_IDLE)
        )

    if ok_for_mdi():
        c.mode(linuxcnc.MODE_MDI)
        c.wait_complete()  # wait until mode switch executed
        print("OK, running...")
        try:
            control_robot(c)
        except KeyboardInterrupt:
            c.abort()
            sys.exit(1)
    else:
        print("Not OK for running. Check that the robot is homed and idle.")
        sys.exit(1)

if __name__ == "__main__":
    try:
        main()
    except linuxcnc.error as e:
        print("error: ", e)
        print("is LinuxCNC running?")
        sys.exit(1)
```

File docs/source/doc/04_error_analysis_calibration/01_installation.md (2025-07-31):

# Installation and Basic Usage

1. **Install dependencies**: Use `uv` or `pip` to create a virtual environment and install the required Python packages.

   - With `uv`:

     ```bash
     uv venv && source .venv/bin/activate && uv pip install -r requirements.txt
     ```

   - With `pip`:

     ```bash
     python -m venv .venv && source .venv/bin/activate && pip install -r requirements.txt
     ```

2. **Prepare the data**: The system requires both gantry position data (CSV) and OptiTrack motion capture data (CSV) in the expected formats (see {ref}`sec:data_format` section).

3. **Add a configuration file**: Create a `config.json` file with the calibration settings.

4. **Run the calibration script**: Execute the calibration script `run_calibration.py` to generate a `calibration.json` file with the alignment and correction parameters.

5. **Visualize the results**: Use the plotting scripts to visualize the results.

See {ref}`sec:usage` section for more details on how to use the scripts.

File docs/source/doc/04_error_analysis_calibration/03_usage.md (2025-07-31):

(sec:usage)=

# Usage

:::{important}
Remember that the calibration process assumes that the gantry data is the commanded position of the gantry robot and the OptiTrack data is the actual position of the gantry robot. After the calibration is complete, the scripts that evaluate the calibration results correct the OptiTrack data with the calibration parameters.
:::

We will use the measurement `2025-04-09` (located in the `calibration/measurements/2025-04-09/` directory of the repository) to explain how to use the scripts. To execute the code it is recommended to change the working directory to the measurement directory:

```bash
cd calibration/measurements/2025-04-09/
```

This way the scripts will be able to find the data files without needing to specify them by command line arguments.

## Raw Gantry and OptiTrack Path Visualization

The raw gantry and OptiTrack data can be visualized using the `plot_movement_gantry.py` and `plot_movement_optitrack.py` scripts, respectively. For example, to visualize the OptiTrack data, run:

```bash
python ../../src/plot_movement_optitrack.py
```

It will open a window with the OptiTrack data visualization. {numref}`fig:plot_movement_optitrack` below shows the OptiTrack data visualization.

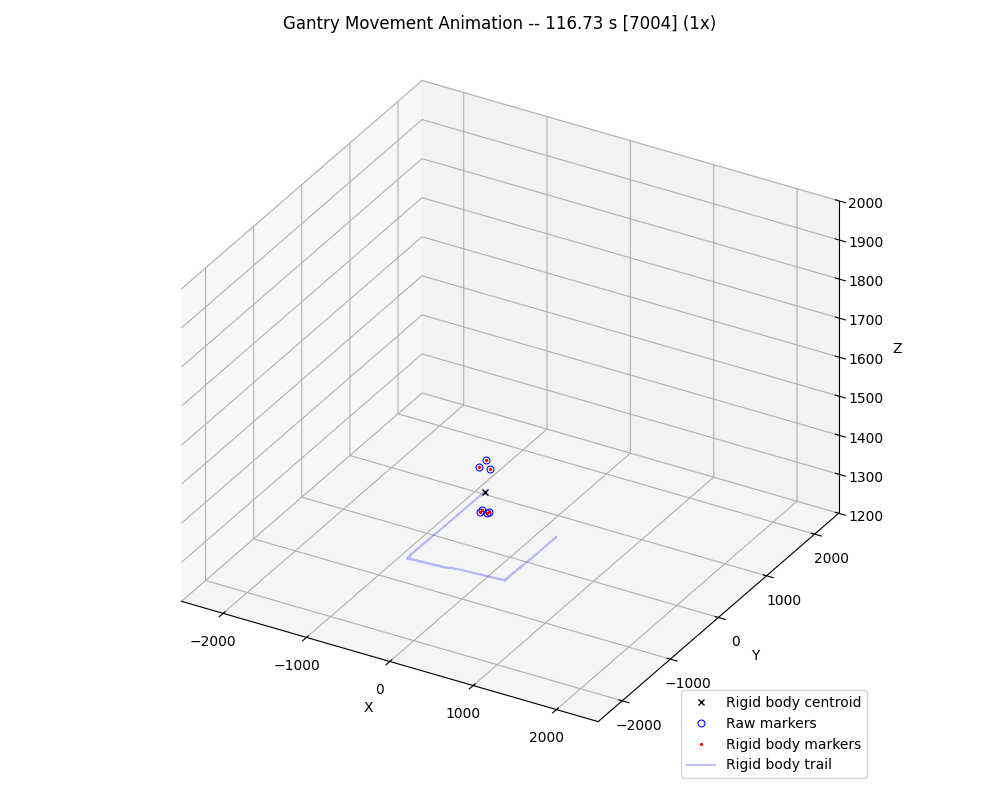
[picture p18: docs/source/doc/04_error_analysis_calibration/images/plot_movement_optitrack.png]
:::{figure} images/plot_movement_optitrack.png
:width: 600px
:name: fig:plot_movement_optitrack

OptiTrack data visualization showing the 3D trajectory of the gantry robot as measured by the motion capture system.
:::

You can use the keyboard to control the playback of the data. The available controls are shown when the script is executed:

```text
Animation Controls:
------------------
Space: Play/Pause
PageUp/PageDown: Increase/Decrease playback speed
Shift + PageUp/PageDown: Increase/Decrease playback speed by 5x
m/n: Step forward/backward 1 frame
M/N: Step forward/backward 60 frames
Ctrl+m/Ctrl+n: Step forward/backward 600 frames
i/o: Jump to start/end
```

## Calibration Configuration

Before running the calibration script, you need to create a JSON configuration file, by default named `config.json`. The configuration file defines the calibration parameters, data processing options, and analysis settings. The configuration format follows the structure defined in the `CalibrationConfig` class in `data.py`, allowing you to customize:

- Alignment parameters and optimization settings
- Correction (calibration) parameters and methods  
- Frame skipping ranges for excluding poor tracking data
- Optimization tolerances and display options

The contents of the configuration file used for the `2025-04-09` measurement are the following:

```json
{
  "alignment": {
    "init_params": [2500, 2500, -2500, 0, 0, -1.5707963267948966, 50],
    "max_rotation": 0.098174770424681,
    "rotation_center": [2500, 2500, -750],
    "optimization": {
      "method": "Powell",
      "tolerance": 1e-9,
      "display": true
    }
  },
  "calibration": {
    "enabled": true,
    "optimization": {
      "method": "Powell", 
      "tolerance": 1e-9,
      "display": true
    }
  },
  "skip_frames": {
    "enabled": true,
    "ranges": [
      [8800, 9200],
      [28750, 29550],
      [55900, 56050],
      [57870, 58000]
    ]
  }
}
```

Some important considerations:

- The initialization parameters in the `init_params` field of the `alignment` section are the initial values for the optimization of the calibration alignment step. If not specified, default values of 0 are used. The parameters are the following, in the order they are used in the optimization (see the `get_processed_data` function in the `data.py` file):

  - `x_shift`: Translation along the x-axis in mm
  - `y_shift`: Translation along the y-axis in mm
  - `z_shift`: Translation along the z-axis in mm
  - `x_rotation`: Rotation around the x-axis in radians
  - `y_rotation`: Rotation around the y-axis in radians
  - `z_rotation`: Rotation around the z-axis in radians
  - `time_shift`: Time shift in seconds

  :::{important}
  These parameters may need to be set manually for the optimization to converge to the optimal value.
  :::

- The `max_rotation` parameter is the maximum rotation allowed in the optimization for all axes. If not specified or if this value is too large the optimization may not converge to the optimal value.

- The `skip_frames` parameter is a list of frame ranges to skip. The frame ranges are defined as a list of tuples, where each tuple contains the start and end frame of the range. The frame ranges are used to exclude frames with poor tracking quality.

## Run the Calibration

To execute the calibration execute the `run_calibration.py` script:

```bash
python ../../src/run_calibration.py
```

When you run the calibration script, the computed parameters (both alignment and correction) are saved in a `calibration.json` file, which is then used by the plotting and analysis scripts.

The contents of the calibration file used for the `2025-04-09` measurement are the following:

```json
{
  "alignment": [
    2569.064951390571,
    2431.945890597083,
    -2445.8453677141842,
    0.01621568645263669,
    -0.0019764080563279946,
    -1.627993124493423,
    48.529188401692736
  ],
  "correction": [
    0.9990369632649009,
    -0.0023705036806220222,
    -0.0010354716462371396,
    0.003519113620152516,
    1.0024657909515957,
    -0.004752129098771147,
    0.012339767658019774,
    0.003979069253835251,
    1.0001914458552963,
    2.205888871025789e-7,
    3.122118199676554e-7,
    2.3016495733564933e-7,
    -8.883515393297157e-7,
    -4.6904454317380076e-8,
    9.733292477941651e-7,
    9.648396195409736,
    0.8905471886524144,
    4.555186849749805
  ]
}
```

## Run the Parameters Validation

The `check_params.py` script is used to validate the calibration parameters. As explained in the Parameters Validation section, it performs a Jacobian invertibility test and a bounds test.

To run the validation execute the `check_params.py` script:

```bash
python ../../src/check_params.py
```

The script accepts the following parameters to customize the joints and axes bounds:

- `--axis-min`: The minimum value of the X, Y, and Z axes.
- `--axis-max`: The maximum value of the X, Y, and Z axes.
- `--joint-min`: The minimum value of the X, Y, and Z joints.
- `--joint-max`: The maximum value of the X, Y, and Z joints.

## LinuxCNC Configuration for the `calibxyzkins` module

The `calibxyzkins` module included in this project can be used to calibrate the gantry robot with the correction parameters obtained from the calibration process. To use the module, its HAL parameters must be set properly. These parameters can be generated using the `print_calibxyzkins_config.py` script:

```bash
python ../../src/print_calibxyzkins_config.py
```

Which will output the following HAL configuration:

```hal
# Calibration matrix A
setp calibxyzkins.calib-a.xx 0.9990369633
setp calibxyzkins.calib-a.xy 0.00351911362
setp calibxyzkins.calib-a.xz 0.01233976766
setp calibxyzkins.calib-a.yx -0.002370503681
setp calibxyzkins.calib-a.yy 1.002465791
setp calibxyzkins.calib-a.yz 0.003979069254
setp calibxyzkins.calib-a.zx -0.001035471646
setp calibxyzkins.calib-a.zy -0.004752129099
setp calibxyzkins.calib-a.zz 1.000191446

# Calibration matrix B
setp calibxyzkins.calib-b.xx 2.205888871e-07
setp calibxyzkins.calib-b.xy -8.883515393e-07
setp calibxyzkins.calib-b.xz 0
setp calibxyzkins.calib-b.yx 3.1221182e-07
setp calibxyzkins.calib-b.yy -4.690445432e-08
setp calibxyzkins.calib-b.yz 0
setp calibxyzkins.calib-b.zx 2.301649573e-07
setp calibxyzkins.calib-b.zy 9.733292478e-07
setp calibxyzkins.calib-b.zz 0

# Calibration vector C
setp calibxyzkins.calib-c.x 9.648396195
setp calibxyzkins.calib-c.y 0.8905471887
setp calibxyzkins.calib-c.z 4.55518685
```

## Gantry and Calibrated OptiTrack Path Visualization

The gantry and calibrated OptiTrack path can be visualized using the `plot_movement.py` script:

```bash
python ../../src/plot_movement.py
```

:::{note}
The script accepts the `--no-correct` flag to show the OptiTrack position without applying the correction transformation.
:::

{numref}`fig:plot_movement` below shows the gantry and OptiTrack path visualization.

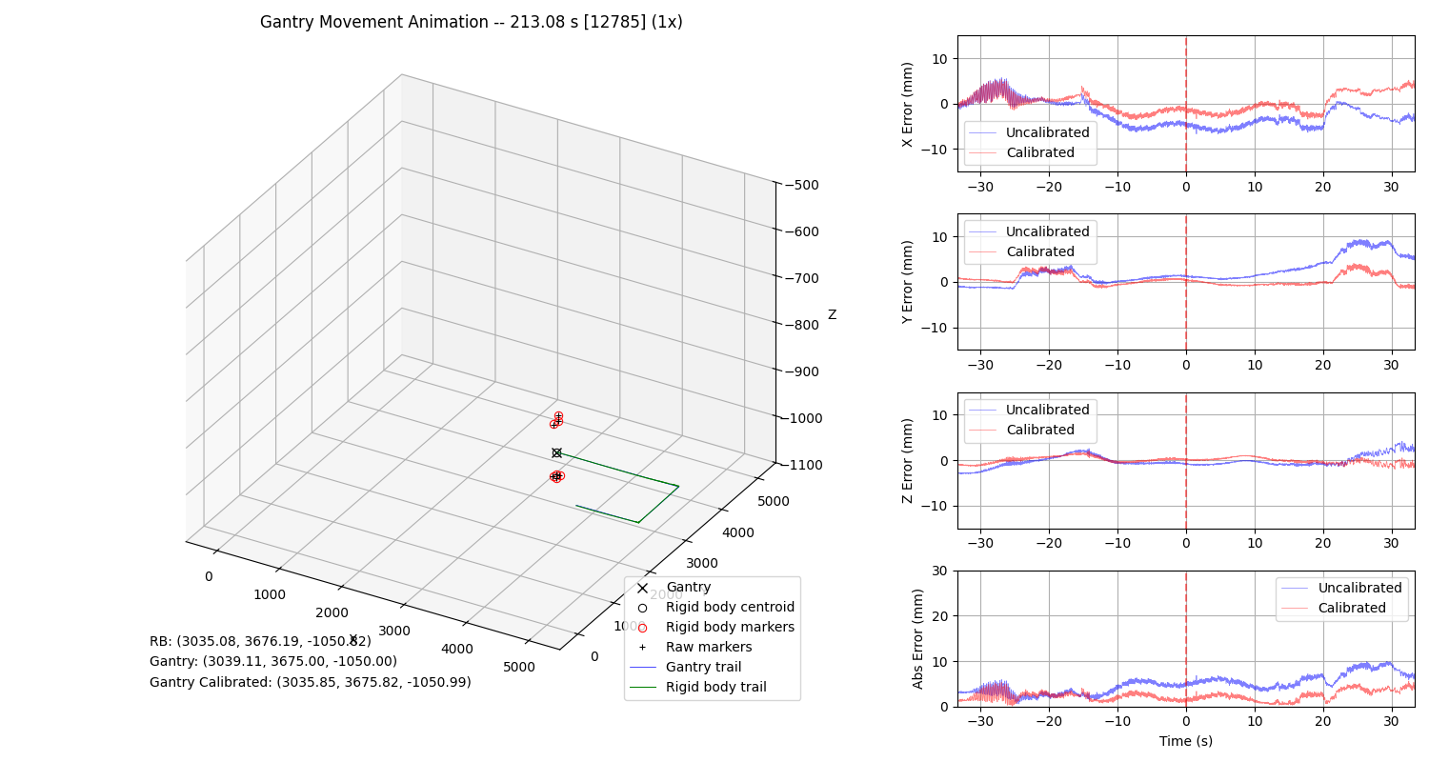
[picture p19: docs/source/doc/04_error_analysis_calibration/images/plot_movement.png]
:::{figure} images/plot_movement.png
:width: 600px
:name: fig:plot_movement

Gantry and calibrated OptiTrack path visualization. The error between the corrected OptiTrack trajectory and the reference gantry data is also shown.
:::

As in the case of the raw data visualization scripts, you can use the keyboard to control the playback of the data.

## Plot Positioning Errors Over Time

The positioning errors between gantry and OptiTrack data over time can be plotted using the `plot_errors.py` script:

```bash
python ../../src/plot_errors.py
```

The script accepts the option `--time-unit` to specify the time unit of the x-axis. The available options are `s` (seconds) and `frames`. The default is `s` (seconds). The `frames` options can be used to check the ranges of frames with poor tracking quality, then they can be skipped by setting them in the configuration file.

The script also accepts the `--no-correct` flag to show the OptiTrack position without applying the correction transformation.

{numref}`fig:plot_errors_no_correct` below shows the positioning errors over time with the `--no-correct` flag, i.e., without applying the correction transformation to the OptiTrack position.

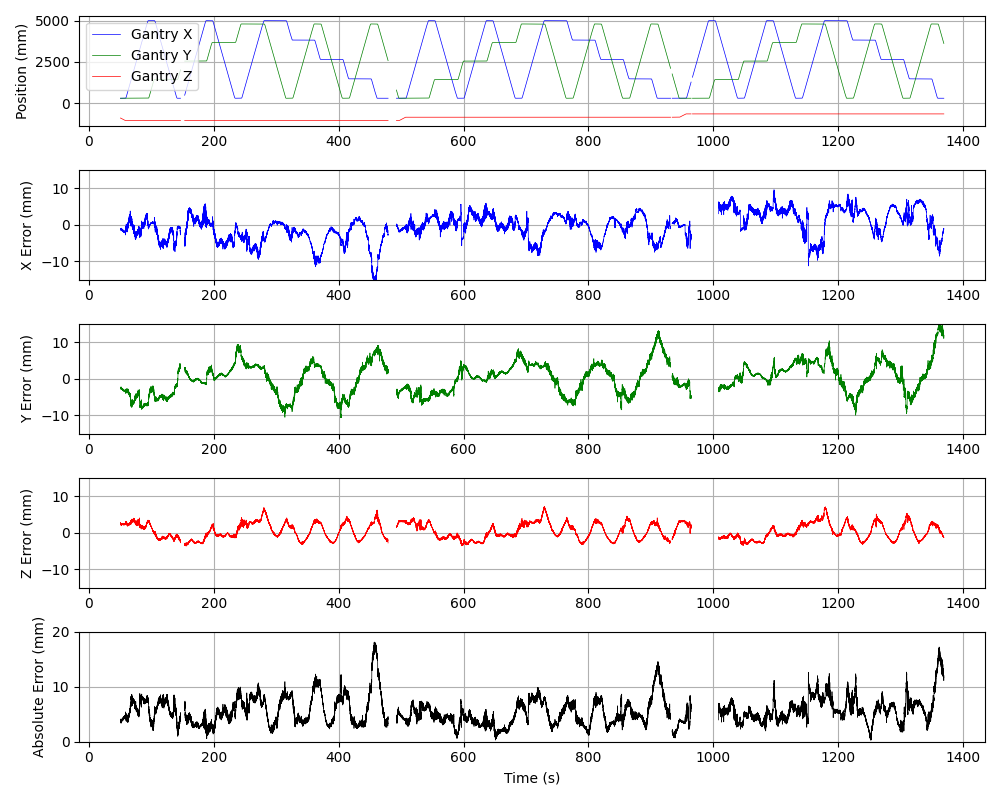
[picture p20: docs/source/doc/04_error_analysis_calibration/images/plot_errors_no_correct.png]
:::{figure} images/plot_errors_no_correct.png
:width: 600px
:name: fig:plot_errors_no_correct

Positioning errors over time before calibration correction, showing systematic deviations between gantry and OptiTrack measurements.
:::

{numref}`fig:plot_errors` below shows the positioning errors over time when applying the correction transformation to the OptiTrack position.

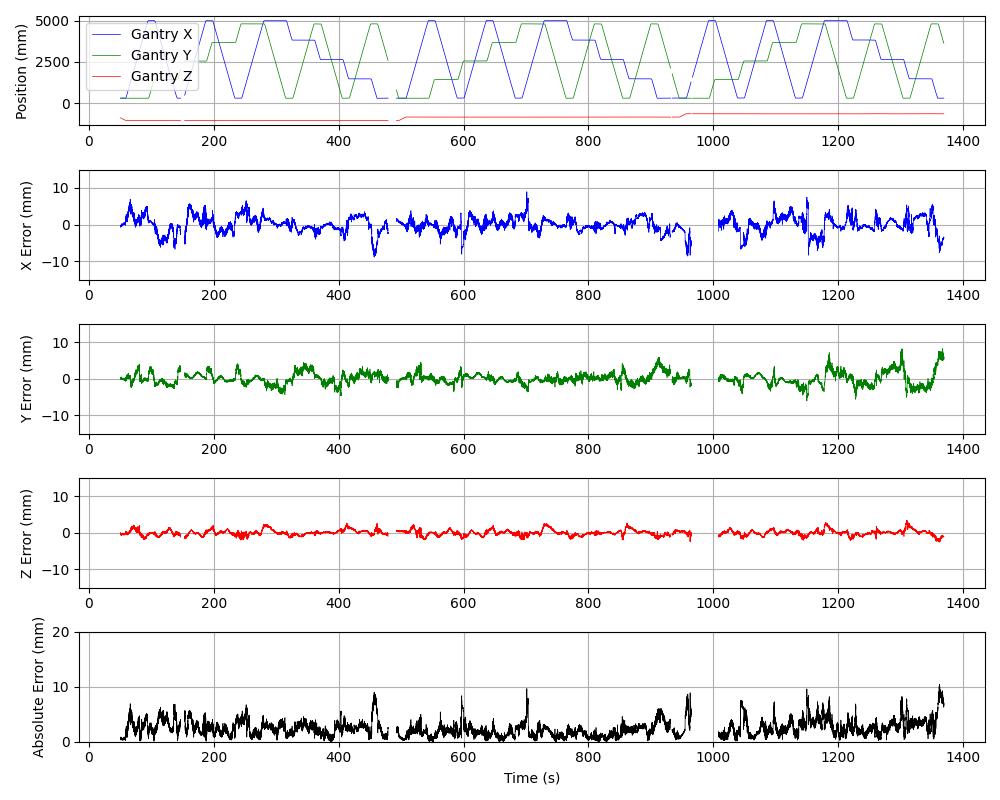
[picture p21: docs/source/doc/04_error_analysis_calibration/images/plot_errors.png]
:::{figure} images/plot_errors.png
:width: 600px
:name: fig:plot_errors

Positioning errors over time after calibration correction, demonstrating significant reduction in systematic positioning errors.
:::

(sec:plot_errors_scatter)=

## Plot Positioning Errors Scatter

Positioning errors scatter plots between gantry and OptiTrack data can be plotted using the `plot_errors_scatter.py` script:

```bash
python ../../src/plot_errors_scatter.py
```

The script also accepts the `--no-correct` flag to show the OptiTrack position without applying the correction transformation.

{numref}`fig:plot_errors_scatter_no_correct` below shows the positioning errors scatter plots with the `--no-correct` flag, i.e., without applying the correction transformation to the OptiTrack position.

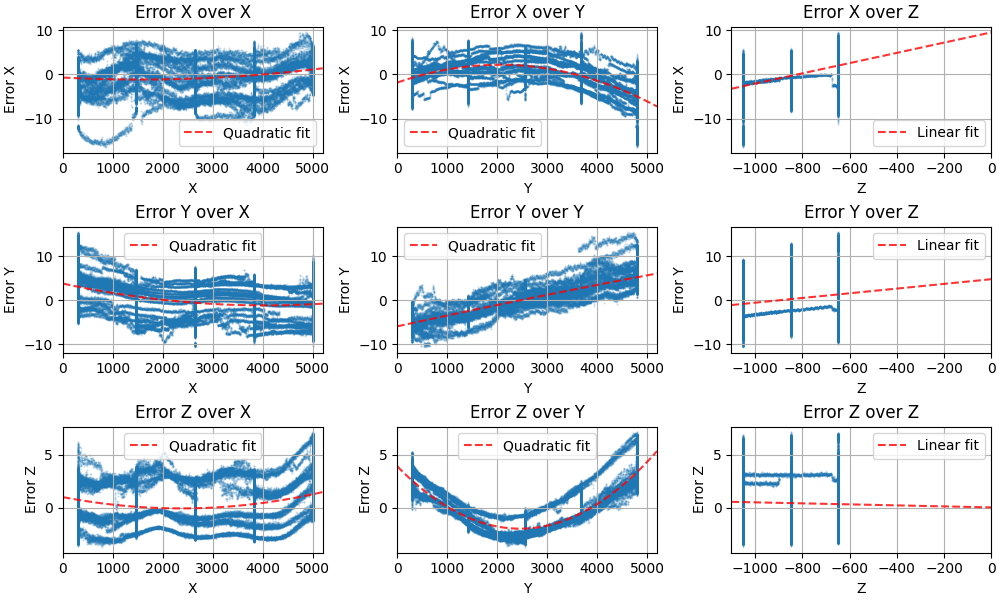
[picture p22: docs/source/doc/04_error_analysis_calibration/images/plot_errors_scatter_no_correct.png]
:::{figure} images/plot_errors_scatter_no_correct.png
:width: 600px
:name: fig:plot_errors_scatter_no_correct

Positioning errors scatter plots before calibration correction, revealing systematic patterns in positioning deviations across the workspace.
:::

{numref}`fig:plot_errors_scatter` below shows the positioning errors scatter plots when applying the correction transformation to the OptiTrack position.

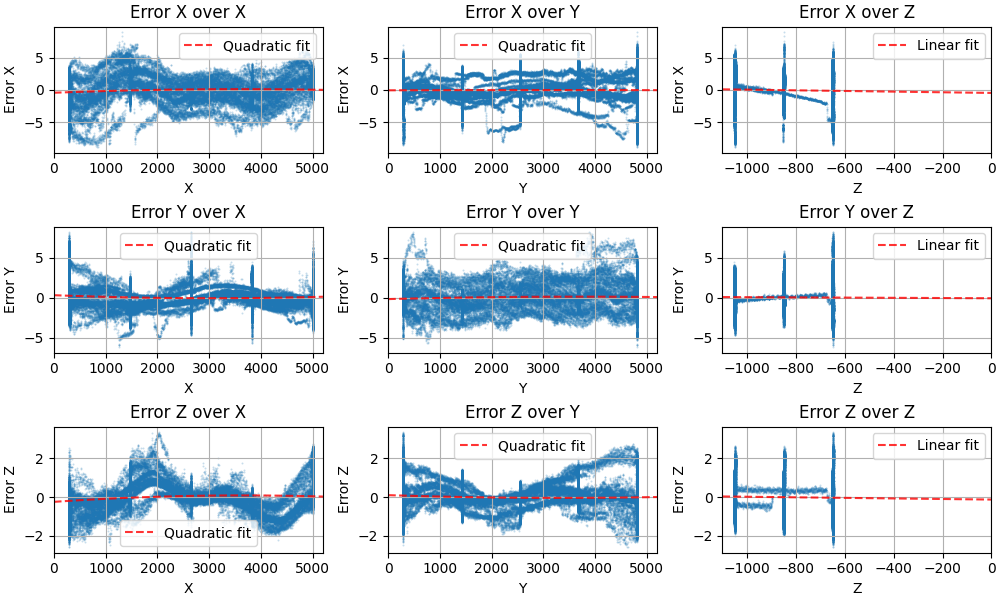
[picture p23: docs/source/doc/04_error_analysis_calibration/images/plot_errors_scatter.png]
:::{figure} images/plot_errors_scatter.png
:width: 600px
:name: fig:plot_errors_scatter

Positioning errors scatter plots after calibration correction, showing the elimination of systematic error patterns.
:::

## Plot Positioning Errors Probability Distributions

The positioning errors probability distribution can be plotted using the `plot_errors_probability.py` script:

```bash
python ../../src/plot_errors_probability.py
```

By default the script plots the probability distribution of the positioning errors for the x, y, and z axes. {numref}`fig:plot_errors_probability` below shows the obtained probability distributions.

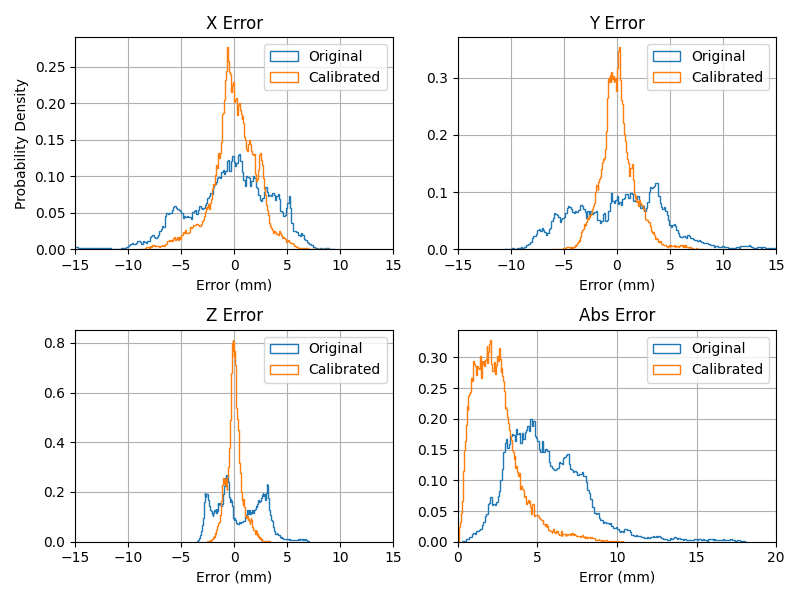
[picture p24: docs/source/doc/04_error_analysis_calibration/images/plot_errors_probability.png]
:::{figure} images/plot_errors_probability.png
:width: 600px
:name: fig:plot_errors_probability

Positioning errors probability distributions showing the statistical distribution of positioning errors after calibration for each axis.
:::

The script accepts the `--cumulative` flag to plot the cumulative distribution function of the positioning errors. {numref}`fig:plot_errors_probability_cumulative` below shows the cumulative distribution function of the positioning errors for the x, y, and z axes.

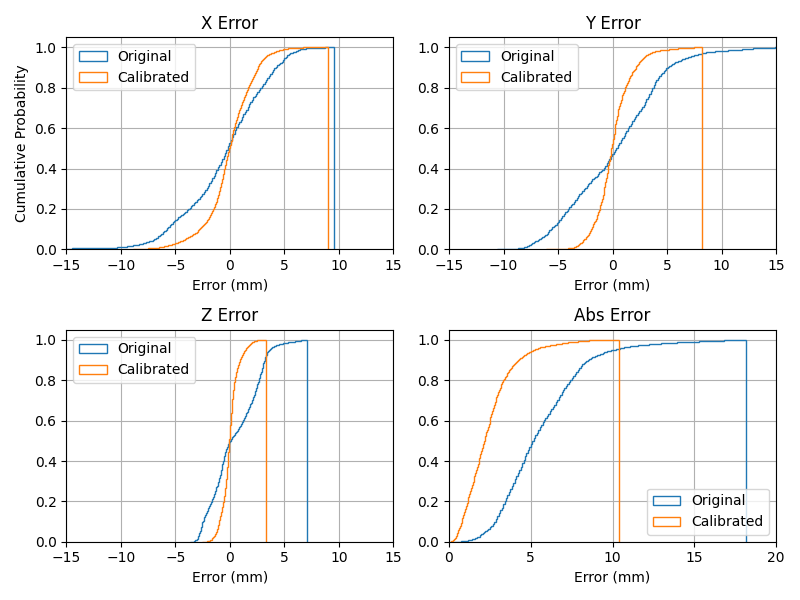
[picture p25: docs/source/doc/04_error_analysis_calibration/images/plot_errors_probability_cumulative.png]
:::{figure} images/plot_errors_probability_cumulative.png
:width: 600px
:name: fig:plot_errors_probability_cumulative

Cumulative distribution function of positioning errors.
:::

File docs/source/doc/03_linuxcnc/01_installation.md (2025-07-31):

(sec:linuxcnc_installation)=

# Installation

LinuxCNC is available for installation from the official repositories of Debian and Ubuntu Linux distributions. For our gantry robot system, we installed the Debian distribution with the XFCE desktop environment. To install Debian, go to <https://www.debian.org/>, download the ISO image, and follow the installation instructions.

Once the operating system is installed, follow these steps to install LinuxCNC:

1. Update the system's package index by running the following commands:

   ```sh
   sudo apt-get update
   sudo apt-get dist-upgrade
   ```

2. Install LinuxCNC using the following command:

   ```sh
   sudo apt-get install linuxcnc-uspace linuxcnc-uspace-dev
   ```

   LinuxCNC requires a real-time Linux kernel. The `linuxcnc-uspace` package includes `linux-image-amd64` as a dependency, which provides the Linux kernel with `PREEMPT_RT` patches to convert it into a real-time system.

3. Install `mesaflash`, the MESA board configuration and diagnostic tool, using the following command:

   ```sh
   sudo apt-get install mesaflash
   ```

4. Restart the system. After restarting, the system should be using the real-time kernel. To verify the kernel version in use, run the following command:

   ```sh
   uname -v
   ```

   The output should specify the `PREEMPT_RT` kernel version, similar to the example below:

   ```text
   #1 SMP PREEMPT_RT Fri Oct 6 19:02:35 UTC 2023
   ```

5. Optionally, you can uninstall the standard Linux kernel with the following command:

   ```sh
   sudo apt-get remove linux-image-amd64
   ```

Once the LinuxCNC package is installed, a "CNC" entry will appear in the applications menu, which will contain the following items:

- **Documentation**: LinuxCNC documentation in PDF format, including the user manual and man pages.
- **G-code Quick-Reference**: A quick reference page for G-code commands.
- **Latency Histogram**: Display a latency histogram.
- **Latency Test**: Run a latency test to determine the maximum system latency or jitter.
- **LinuxCNC**: The LinuxCNC launcher, allowing you to select the LinuxCNC configuration to execute.
- **Pncconf wizard**: A wizard for generating LinuxCNC configurations that use MESA boards.
- **Stepconf wizard**: A wizard for generating LinuxCNC configurations that use the parallel port to control stepper motors.

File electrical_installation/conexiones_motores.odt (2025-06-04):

X1 | X2 | Y

Final de carrera

Motor | Rack | Driver
Azul | Azul | Tierra
Negro | Morado | Alimentación 24V
Marrón | Azul rojo | X2.8

Lógica

Motor | Rack | Driver
Rojo | Rojo | X6.1
Negro | Negro | X6.2
Verde | Verde | X6.3
Verde negro | Verde marrón | X6.4
Blanco | Blanco | X6.5
Blanco negro | Blanco amarillo | X6.6
Amarillo | Amarillo | X6.7
Amarillo negro | Amarillo marrón | X6.8
Marrón | Marrón | X6.9
Gris | Gris | X6.10
Naranja | Naranja | X6.11

Alimentación

Motor | Rack | Driver
Amarillo | Amarillo | X5.1
Verde | 1 | X5.2
Azul | 2 | X5.3

Z

Final de carrera

Motor | Rack | Driver
Azul | Blanco verde | Tierra
Negro | Morado | Alimentación 24V
Marrón | Azul rojo | X2.8

Lógica

Motor | Rack | Driver
Rojo | Rojo | X6.1
Gris | Gris | X6.2
Blanco | Blanco | X6.3
Marrón | Marrón | X6.4
Verde | Verde | X6.5
Amarillo | Amarillo | X6.6
Azul | Azul | X6.7
Rosa | Rosa | X6.8

Alimentación

Motor | Rack | Driver
Blanco | 4 | X5.1
Marrón | 2 | X5.2
Azul | 3 | X5.3
Negro | 1 | X5.4

Z Rotación

Final de carrera

Motor | Rack | Driver
Azul | Blanco verde | Tierra
Negro | Morado | Alimentación 24V
Marrón | Azul rojo | X2.8

Lógica

Motor | Rack | Driver
Rojo | Rojo | X6.1
Azul | Azul | X6.2
Blanco | Blanco | X6.3
Marrón | Marrón | X6.4
Amarillo | Amarillo | X6.5
Verde | Verde | X6.6
Rosa | Rosa | X6.7
Gris | Gris | X6.8

Alimentación

Motor | Rack | Driver
Blanco | 4 | X5.1
Marrón | 2 | X5.2
Azul | 3 | X5.3
Negro | 1 | X5.4

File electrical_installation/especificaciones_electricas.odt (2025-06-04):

Especificaciones eléctricas

# Equipos Instalados

Tabla 1: Datos eléctricos de los motores (Igus)

Motor | Eje | Voltaje | Corriente nominal | Corriente de pico | Consumo nominal
MOT-EC-86-C-I-A | X (2) / Y (1) | 48 V | 8.7 A | 26.1 A | 314 W
MOT-AN-S-060-035-060-L-C-AAAC | Z | 24 – 48 V | 4.2 A | 6.3 A | -
MOT-ST-56-L-C-A | Rotación | 24 – 48 V | 4.2 A | 6.3 A | -

Nota: En el caso de los motores brushless (MOT-EC-86-C-I-A) su documentación especifica la corriente nominal y de pico. En el caso de los motores stepper (MOT-AN-S-060-035-060-L-C-AAAC, MOT-ST-56-L-C-A) su documentación solo proporciona la corriente nominal. Para la corriente de pico debemos considerar en los controladores Igus D1 el parámetro de boost current, descrito como:

The Boost Current indicates the increase of the Motor Current during acceleration and deceleration phases. An increase of the Motor Current to the value of the Boost Current is possible for a maximum of 2 s may be set up to 150% (stepper motors), 200% (direct current motors), or 300% (EC/BLDC motors). Activation of the Boost Current depends on the frequency of movement.

Por lo tanto en los motores EC/BLDC, la corriente de pico puede ser hasta 3 veces la corriente nominal, y en los motores stepper hasta 1.5 veces la corriente nominal. Por otra parte también en el manual de los controladores Igus D1 se dice:

The maximum current of a Stepper Motor can be above the indicated rated current. The actual occurring current must be considered for installation.

Any current setting are made at your own risk.

Tabla 2: Datos eléctricos de los controladores (Igus D1)

Voltage Supply | Logic | 12 to 24 V, max. 26 V
| Load | 12 to 48 V, max. 50 V
| Digital I/O | 5 to 24 V, max. 26 V
| Current Drain Logic | Min. 75 mA to 225 mA
| Current Drain Load | 5 mA to 7 A, max 22 A (Boost)
| Current Drain Digital I/O | 35 mA to 1.1 A
Continuous Motor Current | 7A
Boost Current | Output Duration | Max. 2 s
| ST | 10.5 A
| DC | 14 A
| EC/BLDC | 21 A
Load Power Output | Max. 340 W
Peak Power Output | Max. 1000 W
Dissipation Loss | Min. 2,5 W (idle)
| Max. 15 W (full load)
Motor and encoder cable lengths | < 30m
Digital Inputs | 10 Digital Inputs
| Short-Circuit Protected
| Galvanically Separated by Optocoupler
| ULow 10% UB X2.11
| UHigh 60% UB X2.11
| PNP | Pull-Down, internal
| NPN | Pull-Up, internal
| Maximum Frequency DI 1 and DI 2 | 25 kHz
| Maximum Frequency DI 3 to DI 10 | 100 Hz
| Debounce Filter DI 1 to DI 10 (not at Step/Direction Mode) | 10 ms
| Current Drain | 5 V at X2.11 | 5 mA
| | 24 V at X2.11 | 8 mA
Digital Outputs | 5 Digital Outputs
| Short-Circuit Protected
| Galvanically Separated by Optocoupler
| PNP | Pull-Down, internal
| Output Current | Max. 200mA
| Output Voltage | UB at X2.11
Analogue Inputs | Voltage Interval | ± 10V
| Input Resistance | 50 kΩ
| Accuracy | ± 0.1 V
| Signal Filter | 16 ms, level dependent
| ± 10 V Signal | 12 Bit
| 0-10 V Signal | 11 Bit
| Internal Voltage Supply | 10 V ±2%
| | Max. 15 mA
| | Regulated
| | Short Circuit Protected
| External resistor between X4.1 and X4.4 | 700 Ω to 50 kΩ

Tabla 3: Datos eléctricos de los sensores inductivos (Igus INI-AB-I-025-B-AA)

Supply voltage [VCD] | 10 – 30 V
Max. contact voltage [VCD] | 10 – 30 V
Switching current | 100 mA
No-load current | 10 mA
Max. switching frequency | 3000 Hz

Tabla 4: Datos eléctricos de las fuentes de alimentación (MEAN WELL)

| | SDR-240-24 | SDR-960-48
Output | DC voltage | 24V | 48V
| Rated current | 10A | 20A
| Current range | 0 ~ 10A | 0 ~ 20A
| Rated power | 240W | 960W
| Peak current | 15A | 26A
| Peak power (note .6) | 360W (3sec.) | 1248W (3sec.)
| Ripple & noise (max.) (note. 2) | 50mVp-p | 250mVp-p
| Voltage adj. range | 24 ~ 28V | 48 ~ 55V
| Voltage tolerance (note .3) | ±1.0% | ±1.0%
| Line regulation | ±0.5% | ±0.5%
| Load regulation | ±1.0% | ±1.0%
| Setup, rise time | 650ms, 60ms/230VAC | 1000ms, 100ms/230VAC at full load
| Hold up time (typ.) | 20ms/230VAC | 14ms / 230VAC at full load

Notes

1. All parameters NOT specially mentioned are measured at 230VAC input, rated load and 25℃ of ambient temperature.
2. Ripple & noise are measured at 20MHz of bandwidth by using a 12" twisted pair-wire terminated with a 0.1uf & 47uf parallel capacitor.
3. Tolerance includes set up tolerance, line regulation and load regulation.
4. The power supply is considered a component which will be installed into a final equipment. The final equipment must be re-confirmed that it still meets EMC directives.
5. Installation clearances : 40mm on top, 20mm on the bottom, 5mm on the left and right side are recommended when loaded permanently with full power. In case the adjacent device is a heat source, 15mm clearance is recommended.
6. 3 seconds max., please refer to peak loading curves.

# Placas MESA

Se detallan las especificaciones eléctricas para las placas MESA 7I96S y 7I77.

- 7i96S: Ethernet connected motion control interface designed for interfacing up to 5 Axis of step and direction step motor or servo motor drives.

Interface | Parameter | Min | Max | Units | Notes
General | 5V power supply | 4.75 | 5.25 | VDC
| 5V current | - | 250 | mA | No ext. load
Step/dir outputs | Step/dir output high V | 4 | - | V | 10 mA source
| Step/dir output low V | - | 1 | V | 10mA sink
| Step rate | | 10 | MHz
Isolated inputs | Input range | ±5 | ±36 | V
| Input resistance | 4.7 | 5 | kΩ
| Input isolation voltage | - | 100 | VDC
| Maximum input frequency | - | 5 | KHz
Isolated outputs 0 through 3 | Output switched voltage | 0 | 36 | V
| Output switched current | - | 2 | A
| Output resistance | - | 75 | mΩ
| Output isolation voltage | - | 100 | VDC
| Maximum output frequency | - | 5 | kHZ
Isolated outputs 4 and 5 | Output switched voltage AC | 0 | 24 | VAC
| Output switched voltage DC | 0 | 36 | VDC
| Output switched current | - | 100 | mA
| Output resistance | - | 16 | Ω
| Output isolation voltage | - | 300 | VDC
| Maximum output frequency | - | 500 | Hz
Analog spindle output | Input voltage | 5 | 20 | VDC
| Current draw (no ext load) | - | 4 | mA
| Linearity (10 khz PWM) | - | 0.25 | %FS
| 0 offset | - | 25 | mV
| Fs offset | - | -25 | mV
| Frequency response | 250 | - | Hz
| Ripple and noise (10 kHz PWM) | - | 0.1 | %FS
| Output resistance | - | 55 | Ω
High speed encoder input | Input common mode range | -7 | +12 | V
| Input ttl mode threshold | 1.4 | 1.8 | V
| Differential mode impedance | 118 | 122 | Ω
| Count rate | - | 10 | MHz

- 7i77: Daughtercard/breakout board for use with MESA’s 25 pin I/O FPGA cards, designed for interfacing up to 6 Axis of analog servo motor drives and with 48 isolated I/O points for general purpose field I/O use.

Interface | Parameter | Min | Max | Units | Notes
General | 5V power supply | 4.75 | 5.25 | VDC
| 5V current | - | 700 | mA | No ext. load
Field I/O | Vin (field I/O logic power) | 10 | 32 | VDC
| Vin power consumption | - | 1 | W | Typ. 600 mW
| Field power | 5 | 28 | VDC
| Per output current (resistive loads and inductive loads with flyback diode) | - | 350 | mA
| Field output current (inductive loads with no flyback diode) | - | 60 | mA
| Per chip current | - | 1.4 | A
| Input impedance | 20 | 24 | kΩ
Analog outputs | Output accuracy | -0.8 | +0.8 | %FS
| Output current | - | 5mA
| Output resolution | - | 13 | bits
| Ripple and noise | -0.1 | +0.1 | %FS
Enable outputs | Output current | - | 50 | mA
| Open circuit voltage | - | 100 | VDC
| On voltage at 50 mA | - | 1.2 | VDC
Encoder inputs | Input common mode range | -7 | +12 | V
| Input TTL mode threshold | 1.4 | 1.8 | V
| Differential mode impedance | 131 | 135 | Ω
| Count rate (with standard firmware/setup) | - | 2 | MHz

# Análisis

Para el análisis consideramos lo siguiente:

- Cada controlador dispone de una fuente de alimentación para los motores:

Eje | Motor | Fuente | Nombre del controlador
X (1) | MOT-EC-86-C-I-A | SDR-960-48 | D-X1
X (1) | MOT-EC-86-C-I-A | SDR-960-48 | D-X2
Y | MOT-EC-86-C-I-A | SDR-960-48 | D-Y
Z | MOT-AN-S-060-035-060-L-C-AAAC | SDR-240-24 | D-Z
Rotación Z | MOT-ST-56-L-C-A | SDR-240-24 | D-RZ

- Conectaremos las salidas digitales ready, alert, y error de los controladores Igus D1 a las placas MESA, dejando desconectadas las salidas digitales active y reference.
- Usaremos una de las fuentes de 24V (SDR-240-24) para la entrada X1.3 de alimentación lógica de todos los controladores.
- Usaremos una fuente adicional de 5V para las placas MESA y que también usaremos para la entrada X2.11 de alimentación de las entradas y salidas digitales de todos los controladores.

Nota: en el manual de los controladores Igus D1 se proporcionan varios ejemplos de análisis de carga y selección de fuente de alimentación en la sección “4.2.4 Power supply selection”. El análisis que haremos aquí es similar.

## Consumo de los controladores

Se debe proporcionar alimentación en tres entradas del controlador: X1.1 (carga), X1.3 (lógica), y X2.12 (digital I/O). Estas entradas se muestran en las figuras 1 y 2.

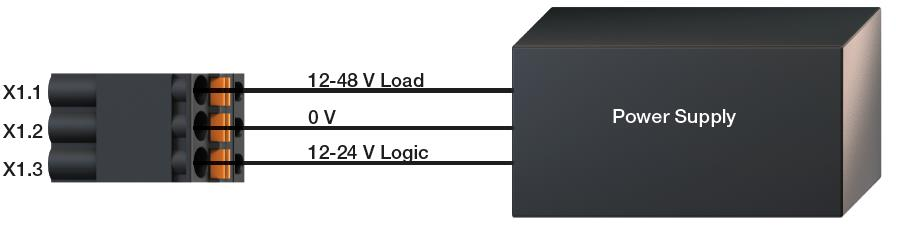
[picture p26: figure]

Figura 1: Entradas de alimentación de carga y lógica

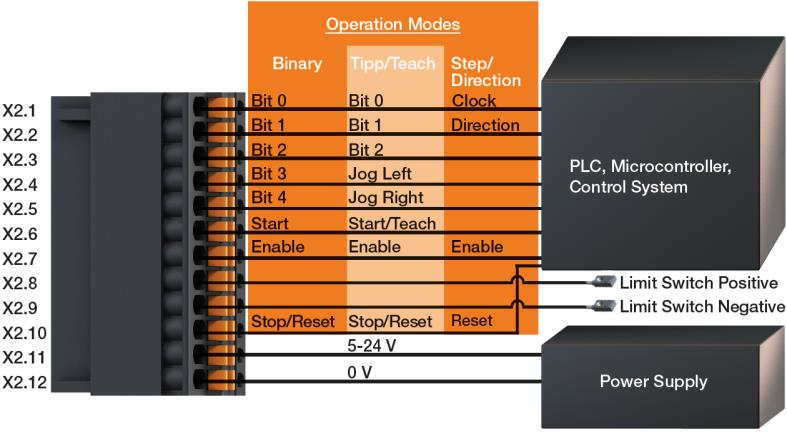
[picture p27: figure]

Figura 2: Salidas digitales y entrada de alimentación de I/O

### Consumo de carga (entrada X1.1)

La entrada X1.1 de alimentación de la carga proporciona la alimentación para los motores, como se muestra en la tabla 1 el voltaje de esta entrada debe estar entre 12 y 48 V, y la corriente suministrada estará entre 5 mA y 22 A.

Controlador | Boost current | Carga (continua) | Carga max. (corto plazo)
D-X1 | 200% | 8.7 A | 17.4 A
D-X2 | 200% | 8.7 A | 17.4 A
D-Y | 200% | 8.7 A | 17.4 A
D-Z | 150% | 4.2 A | 6.3 A
D-RZ | 150% | 4.2 A | 6.3 A

Notas:

- La carga máxima (corto plazo) se calcula como la carga (continua) multiplicada por el factor de boost current.
- Los controladores Igus D1 admiten una boost current máxima de 300% para los motores EC/BLDC, pero en este caso el valor de corriente pico necesaria para nuestros motores sería de 26.1A, el cual supera el máximo tanto de las fuentes de alimentación como del controlador Igus D1. Para asegurar que con nuestros motores la corriente pico no supere los 20A máximos que pueden proporcionar las fuentes de alimentación el factor de boost current debería ser igual o menor a 225%. En el análisis realizado aquí se considera un factor del 200%.
- Los controladores Igus D1 admiten una boost current máxima de 150% para los motores stepper, pero de todas formas el manual también advierte lo siguiente:
    The maximum current of a Stepper Motor can be above the indicated rated current. The actual occurring current must be considered for installation.
    Any current setting are made at your own risk.
- La corriente de los motores se puede monitorizar a traves de la aplicación de osciloscopio en la aplicación web de configuración de los controladores. Alternativamente también se podría monitorizar mediante Modbus/TCP.

### Consumo de lógica (entrada X1.3)

La entrada X1.3 de alimentación lógica proporciona la alimentación a la placa del controlador, como se muestra en la tabla 1 el voltaje de esta entrada debe estar entre 12 y 24 V, y la corriente suministrada estará entre 75 y 225 mA.

Por otra parte también debemos considerar la alimentación para los encoders, que es proporcionada a través de los terminales X6.1 de 5V y X6.1 de 0V. El manual de los controladores dice lo siguiente acerca de estas salidas de alimentación:

Please note that the internal voltage supply can source a maximum of 120 mA.

120 mA a 5V son 600 mW, lo que equivale a una corriente de 25 mA a 24V.

Por lo tanto debemos considerar una corriente de 0.25 A para cada controlador.

### Consumo de entradas y salidas digitales (entrada X2.11)

En la tabla 1 se indica que la corriente de para la I/O digital estará en un rango de entre 35 mA y 1.1 A. Los controladores Igus D1 tienen 5 salidas digitales y según lo indicado en la misma tabla cada salida tiene una corriente máxima de 0.2 A. Por lo tanto podemos asúmir que el valor máximo de corriente de 1.1 A para la I/O digital se dará cuando las 5 salidas digitales estén proporcionando su corriente máxima de 0.2 A.

En nuestro caso consideraremos solo conectadas las salidas digitales ready, alert, y error de los controladores Igus D1 a las placas MESA, dejando desconectadas las salidas digitales active y reference. La corriente que consumirá de estas entradas la placa MESA 7i77 será muy pequeña: como se muestra en los datos de la sección 2, las entradas de la placa 7i77 (Field I/O) tienen una impedancia de entrada de entre 20 y 24 kΩ, por lo tanto para 5V la corriente máxima será de 0.25 mA.

Por lo tanto la corriente de las salidas digitales en nuestro caso será muy pequeña, consideraremos que la corriente máxima que necesitamos será de 0.05 A.

### Resumen de consumos

En la siguiente tabla se resume el consumo de los controladores.

Controlador | Carga | | | Lógica (24V) | I/O (5V)
| Voltaje | I Continua | I Max. (corto plazo)
D-X1 | 48V | 8.7 A | 17.4 A | 0.25 A | 0.05 A
D-X2 | 48V | 8.7 A | 17.4 A | 0.25 A | 0.05 A
D-Y | 48V | 8.7 A | 17.4 A | 0.25 A | 0.05 A
D-Z | 24V | 4.2 A | 6.3 A | 0.25 A | 0.05 A
D-RZ | 24V | 4.2 A | 6.3 A | 0.25 A | 0.05 A

## Consumo de los sensores de límites

Según los datos de la tabla 3, la corriente máxima de los sensores de límites son 100 mA. Considerando 8 sensores de límites la corriente máxima será 8⨯0.1 A = 0.8 A.

## Consumo de las placas MESA

Se detallan los consumos de corriente de las placas MESA 7I96S y 7I77.

### 7I96S

La placa 7i96S se alimenta con 5V. Según las especificaciones mostradas en la sección 2 la placa consume un máximo de 250 mA sin carga.

En nuestro caso consideraremos que conectamos dos de las salidas de step y dos de las salidas direction de la placa con los controladores Igus D1 correspondientes. Según la especificación de la tabla 1, a 5V las entradas digitales de los controladores Igus D1 tienen una corriente de entrada de 5 mA. Por lo tanto la placa deberá suministrar como máximo 4⨯5 mA = 20 mA adicionales.

Por lo tanto en total la placa consumirá un máximo de 270 mA.

### 7I77

La placa 7i77 se alimenta con 5V. Según las especificaciones mostradas en la sección 2 la placa consume un máximo de 700 mA sin carga.

En nuestro caso:

- Para el control de los motores brushless conectamos tres de las salidas analógicas de ±10V de la placa 7i77 a los controladores correspondientes. Según las especificaciones eléctricas de los controladores Igus D1 mostradas en la tabla 2, las entradas analógicas tienen una resistencia de entrada de 50 kΩ, por lo tanto la corriente máxima será de 3⨯10/50k A = 0.6 mA ≅1 mA.
- Conectamos 5 de las salidas de enable de la placa 7i77 a los controladores. Las entradas enable de los controladores son entradas digitales que, según las especificaciones eléctricas de la tabla 2, a 5V tienen una corriente de entrada de 5 mA. Por lo tanto la placa deberá suministrar como máximo 5⨯5 mA = 25 mA adicionales.
- Conectamos las salidas digitales ready, alert, y error de cada controlador a las entradas de Field I/O de las placa 7i77. Para ello usaremos niveles lógicos de 5V. Para usar las entradas de Field I/O de la placa 7i77 proporcionaremos 24V en el terminal VIN y 5V en los terminales VFIELD del bloque TB2. El consumo de VIN es de aproximadamente 600 mW o 25 mA a 24V.

Por lo tanto, en total la placa consumirá 700 + 1 + 25 mA = 726 mA de alimentación a 5V, y 25 mA de alimentación a 24V.

## Resumen de consumos totales

- Alimentación a 48V:
  Consumo máximo = 17.4 A (controlador D-X1) + 17.4 A (controlador D-X2) + 17.4 A (controlador D-Y) = 52.2 A.
- Alimentación a 24V:
  Consumo máximo = 6.3 A (controlador D-Z) + 6.3 A (controlador D-RZ) + 5⨯0.25 A (alimentación lógica de controladores) + 0.8 A (sensores de límites) + 0.025 A (alimentación Field I/O de la placa MESA 7i77) = 14.675 A.
- Alimentación a 5V:
  Consumo máximo: 0.270 A (placa MESA 7i96S) + 0.726 mA (placa MESA 7i77) + 5⨯0.05 (salidas I/O de controladores) = 1.246 A.

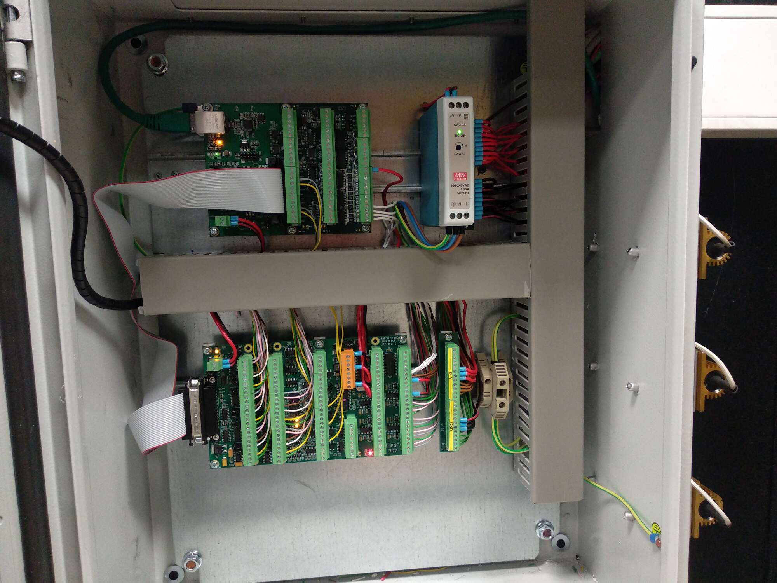
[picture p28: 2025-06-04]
electrical_installation/photos/IMG_20240304_165345.jpg

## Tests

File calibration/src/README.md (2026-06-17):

# Gantry Robot Error Analysis and Calibration

This directory contains Python scripts and utilities for analyzing and calibrating the gantry robot system. The system integrates OptiTrack motion capture data with gantry robot position data to perform error analysis and calibration.

**important**: It is assumed that the gantry data is the commanded position of the gantry robot and the OptiTrack data is the actual position of the gantry robot. After the calibration is complete it can be evaluated with several scripts, which correct the OptiTrack data with the calibration parameters and compare the obtained positions with the reference gantry data.

## System Overview

The system consists of several scripts to process and analyze the data:

1. **Raw Data Visualization**: `plot_movement_gantry.py` and `plot_movement_optitrack.py` scripts to visualize the raw gantry and OptiTrack data before calibration.
2. **Calibration**: `run_calibration.py` is the script that processes the raw data, performing the following steps:
   - **Alignment**: Temporal and spatial alignment of OptiTrack and gantry robot coordinate systems using translation, rotation, and time shift transformations.
   - **Correction**: Non-orthogonal and non-linear transformation of the OptiTrack data to correct errors intrinsic to the gantry robot.

3. **Analysis**: Various scripts for plotting and analyzing the gantry and OptiTrack data, which can be executed after the calibration is complete:
   - `check_params.py`: Check the calibration parameters.
   - `print_calibxyzkins_config.py`: Print the HAL configuration for the `calibxyzkins` module.
   - `plot_movement.py`: Visualize the gantry and OptiTrack path.
   - `plot_errors.py`: Plot positioning errors over time.
   - `plot_errors_scatter.py`: Plot positioning errors scatter plots.
   - `plot_errors_probability.py`: Plot positioning errors probability distributions.

After the calibration is performed, the calibration parameters can be used to correct the gantry position data with the `calibxyzkins` module of LinuxCNC included in this repository.

## Calibration Process

The calibration process performs two steps: **alignment** and **correction**.

### Step 1: Alignment

First, the OptiTrack data must be aligned with the gantry data to account for differences in coordinate systems and timing. This alignment process involves finding the following parameters:

- **Translation**: Shifts in X, Y, and Z axes
- **Rotation**: Rotations around X, Y, and Z axes. By default the rotation center is `(2500, 2500, -750)`, but it may be changed.
- **Time Shift**: Temporal alignment to account for timing differences.

The alignment parameters are found using numerical optimization with the `scipy.optimize.minimize` function (Powell method by default). The objective to minimize is selectable via the `objective` setting: the mean squared error (`mse`, the default) or the mean Euclidean distance (`mean_distance`) between the gantry and the aligned OptiTrack positions.

### Step 2: Correction

Analysis of scatter plots of the positioning errors (see "Plot Positioning Errors Scatter" section in Usage Examples below) reveals clear patterns in positioning errors:

- **Y-axis position affects errors in all axes**
- **X-axis position affects errors in the Y-axis**
- **Z-axis position affects errors in X and Y axes**

These systematic deviations can be corrected by applying a coordinate transformation when controlling the gantry robot. For this we consider a general coordinate transformation with both first-order and second-order components:

$$
\begin{bmatrix}
x' \\ y' \\ z'
\end{bmatrix} =
\underbrace{
\begin{bmatrix}
a_{11} & a_{12} & a_{13} \\ a_{21} & a_{22} & a_{23} \\ a_{31} & a_{32} & a_{33}
\end{bmatrix}
}_{\normalsize \mathbf{A}}
\begin{bmatrix}
x \\ y \\ z
\end{bmatrix} +
\underbrace{
\begin{bmatrix}
b_{11} & b_{12} & 0 \\ b_{21} & b_{22} & 0 \\ b_{31} & b_{32} & 0
\end{bmatrix}
}_{\normalsize \mathbf{B}}
\begin{bmatrix}
x^2 \\ y^2 \\ z^2
\end{bmatrix} +
\underbrace{
\begin{bmatrix}
c_1 \\ c_2 \\ c_3
\end{bmatrix}
}_{\normalsize \mathbf{c}}
$$

where $x, y, z$ are the aligned OptiTrack position coordinates (the actual position of the gantry robot), $x', y', z'$ are the corrected position coordinates (the target position for the gantry control), and $\mathbf{A}, \mathbf{B}, \mathbf{c}$ are the transformation matrices and vector that need to be optimized.

**Note**: The third column of the second-order matrix $\mathbf{B}$ is set to zero because the Z-axis measurement interval is small, making the $z^2$ term unreliable if $z$ is extrapolated.

This transformation consists of:

1. Matrix $\mathbf{A}$: Linear transformation that handles scaling, rotation, and shear.
2. Matrix $\mathbf{B}$: Quadratic transformation that corrects non-linear distortions.
3. Vector $\mathbf{c}$: Constant offset.

The correction parameters are found by minimizing the error between the corrected OptiTrack positions and the gantry positions, with the objective selectable via the `objective` setting. Because the transformation is linear in $\mathbf{A}, \mathbf{B}, \mathbf{c}$, the mean squared error (`mse`, the default) is minimized with `numpy.linalg.lstsq`, while the mean Euclidean distance (`mean_distance`) is minimized iteratively with `scipy.optimize.minimize` (Powell method by default).

## Parameters Validation

The `calibxyzkins` module of LinuxCNC included in this repository uses the Newton-Raphson algorithm to solve the inverse kinematics problem: given desired axes positions $x', y', z'$, it finds the corresponding joint positions $x, y, z$ that satisfy the transformation equation:

$$\mathbf{f}(x, y, z) = \mathbf{A} \begin{bmatrix} x \\ y \\ z \end{bmatrix} + \mathbf{B} \begin{bmatrix} x^2 \\ y^2 \\ z^2 \end{bmatrix} + \mathbf{c} = \begin{bmatrix} x' \\ y' \\ z' \end{bmatrix}$$

To ensure the calibration parameters are valid we include the `check_params.py` script, which performs the following validation tests:

### 1. Jacobian Invertibility Test

The Newton-Raphson method requires computing the Jacobian matrix of the transformation function:

$$\mathbf{J} = \frac{\partial \mathbf{f}}{\partial [x, y, z]} = \mathbf{A} + 2 \cdot \text{diag}(x, y, z) \cdot \mathbf{B}$$

The Jacobian matrix must be invertible throughout the robot's workspace. This is tested using an approach based on the Neumann series.

The Neumann series states that $(\mathbf{I} - \mathbf{T})$ is invertible if $\|\mathbf{T}\| < 1$, where $\mathbf{I}$ is the identity matrix and $\|\cdot\|$ denotes a matrix norm.

For a matrix of the form $\mathbf{X} + \mathbf{Y} = \mathbf{X}(\mathbf{I} + \mathbf{X}^{-1}\mathbf{Y})$, the matrix has an inverse if $\|\mathbf{X}^{-1}\mathbf{Y}\| < 1$.

Applying this to our Jacobian:

- $\mathbf{X} = \mathbf{A}$
- $\mathbf{Y} = 2 \cdot \text{diag}(x, y, z) \cdot \mathbf{B}$

Therefore, the Jacobian $\mathbf{J}$ is invertible if $\mathbf{A}$ is invertible and $\|2 \cdot \mathbf{A}^{-1} \cdot \text{diag}(x, y, z) \cdot \mathbf{B}\| < 1$ for the maximum absolute values of $x, y, z$ in the joint space bounds.

This condition is checked in the `check_params.py` script using both the 1-norm and infinity-norm.

### 2. Bounds Test

The coordinate transformation must respect the physical limits of the robot, i.e., the desired axes positions $(x', y', z')$ must be within the robot's axes limits, and the corresponding joint positions $(x, y, z)$ computed by the inverse kinematics must be within the robot's joint limits.

This condition is checked in the `check_params.py` script by finding the minimum and maximum values that each joint can reach when the axes positions are constrained to their limits. These values must fall within the specified joint limits of the robot for the parameters to be valid.

## Installation and Usage

1. **Install dependencies**: Use `uv` or `pip` to create a virtual environment and install the required Python packages.
   - With `uv`:

     ```bash
     uv venv && source .venv/bin/activate && uv pip install -r requirements.txt
     ```

   - With `pip`:

     ```bash
     python -m venv .venv && source .venv/bin/activate && pip install -r requirements.txt
     ```

2. **Prepare the data**: The system requires both gantry position data (CSV) and OptiTrack motion capture data (CSV) in the expected formats (see Data Format section below).

3. **Add a configuration file**: Create a `config.json` file with the calibration settings.

4. **Run the calibration script**: Execute the calibration script `run_calibration.py` to generate a `calibration.json` file with the alignment and correction parameters.

5. **Visualize the results**: Use the plotting scripts to visualize the results.

See the Usage Example section below for more details.

## Data Format

### Gantry Data (CSV)

The gantry data is a CSV file with the following columns:

- `time` - Unix time (seconds since 1970-01-01 00:00:00 UTC) as a floating-point number.
- `x`, `y`, `z` - Position coordinates in mm as floating-point numbers.

### OptiTrack Data (CSV)

The OptiTrack data is the CSV exported from the OptiTrack Motive software. The format follows this structure:

- **Line 1**: Header with metadata (format version, take name, capture frame rate, export frame rate, start time, total frames, rotation type, length units, coordinate space, etc.)
- **Line 2**: Blank line
- **Line 3**: Object types for each column (e.g., "Rigid Body", "Rigid Body Marker", "Marker")
- **Line 4**: Object names for each column (e.g., "Grua", "Grua:Marker1", "Active 1", "Unlabeled 1007")
- **Line 5**: Unique object IDs (hexadecimal identifiers for each marker/object)
- **Line 6**: Data types for each column ("Rotation" or "Position")
- **Line 7**: Column headers ("Frame", "Time (Seconds)", "X", "Y", "Z", "W" for quaternion rotation, then "X", "Y", "Z" for position coordinates)
- **Line 8 onwards**: Data rows containing:
  - Frame number (integer)
  - Time in seconds (floating-point)
  - Rotation and/or position coordinates.

**Note**: Missing or untracked data points appear as empty cells in the CSV.

## Usage Examples

We will use the measurement `2025-04-09` (located in `../measurements/2025-04-09/`) to explain the code functionality. To execute the code it is recommended to change the working directory to the measurement directory:

```bash
cd ../measurements/2025-04-09/
```

This way the scripts will be able to find the data files without needing to specify them by command line arguments.

### Gantry and OptiTrack Path Visualization

The raw gantry and OptiTrack data can be visualized using the `plot_movement_gantry.py` and `plot_movement_optitrack.py` scripts, respectively. For example, to visualize the OptiTrack data, run:

```bash
python ../../src/plot_movement_optitrack.py
```

It will open a window with the OptiTrack data visualization. The image below shows the OptiTrack data visualization.

OptiTrack data visualization

You can use the keyboard to control the playback of the data. The available controls are shown when the script is executed:

```text
Animation Controls:
------------------
Space: Play/Pause
PageUp/PageDown: Increase/Decrease playback speed
Shift + PageUp/PageDown: Increase/Decrease playback speed by 5x
m/n: Step forward/backward 1 frame
M/N: Step forward/backward 60 frames
Ctrl+m/Ctrl+n: Step forward/backward 600 frames
i/o: Jump to start/end
```

### Calibration Configuration

Before running the calibration script, you need to create a JSON configuration file, by default named `config.json`. The configuration file defines the calibration parameters, data processing options, and analysis settings. The configuration format follows the structure defined in the `CalibrationConfig` class in `data.py`, allowing you to customize:

- Alignment parameters, objective, and `minimize_options` settings
- Correction parameters, objective, and `minimize_options` settings
- Frame skipping ranges for excluding poor tracking data

The contents of the configuration file used for the `2025-04-09` measurement are the following:

```json
{
  "alignment": {
    "init_params": [2500, 2500, -2500, 0, 0, -1.5707963267948966, 50],
    "max_rotation": 0.098174770424681,
    "rotation_center": [2500, 2500, -750],
    "objective": "mse",
    "minimize_options": {
      "method": "Powell",
      "tolerance": 1e-9,
      "display": true
    }
  },
  "correction": {
    "enabled": true,
    "objective": "mse",
    "minimize_options": {
      "method": "Powell",
      "tolerance": 1e-9,
      "display": true
    }
  },
  "skip_frames": {
    "enabled": true,
    "ranges": [
      [8800, 9200],
      [28750, 29550],
      [55900, 56050],
      [57870, 58000]
    ]
  }
}
```

Some important considerations:

- The initialization parameters in the `init_params` field of the `alignment` section are the initial values for the optimization of the calibration alignment step. If not specified, default values of 0 are used. The parameters are the following, in the order they are used in the optimization (see the `get_processed_data` function in `data.py`):

  - `x_shift`: Translation along the x-axis in mm
  - `y_shift`: Translation along the y-axis in mm
  - `z_shift`: Translation along the z-axis in mm
  - `x_rotation`: Rotation around the x-axis in radians
  - `y_rotation`: Rotation around the y-axis in radians
  - `z_rotation`: Rotation around the z-axis in radians
  - `time_shift`: Time shift in seconds

  Important: These parameters may be needed to be set manually for the optimization to converge to the optimal value.

- The `max_rotation` parameter is the maximum rotation allowed in the optimization for all axes. If not specified or if this value is too large the optimization may not converge to the optimal value.

- The `skip_frames` parameter is a list of frame ranges to skip. The frame ranges are defined as a list of tuples, where each tuple contains the start and end frame of the range. The frame ranges are used to exclude frames with poor tracking quality.

### Run the calibration

To execute the calibration execute the `run_calibration.py` script:

```bash
python ../../src/run_calibration.py
```

When you run the calibration script, the computed parameters (both alignment and correction) are saved in a `calibration.json` file, which is then used by the plotting and analysis scripts.

The contents of the calibration file used for the `2025-04-09` measurement are the following:

```json
{
  "alignment": [
    2569.064951390571,
    2431.945890597083,
    -2445.8453677141842,
    0.01621568645263669,
    -0.0019764080563279946,
    -1.627993124493423,
    48.529188401692736
  ],
  "correction": [
    0.9990369632649009,
    -0.0023705036806220222,
    -0.0010354716462371396,
    0.003519113620152516,
    1.0024657909515957,
    -0.004752129098771147,
    0.012339767658019774,
    0.003979069253835251,
    1.0001914458552963,
    2.205888871025789e-7,
    3.122118199676554e-7,
    2.3016495733564933e-7,
    -8.883515393297157e-7,
    -4.6904454317380076e-8,
    9.733292477941651e-7,
    9.648396195409736,
    0.8905471886524144,
    4.555186849749805
  ]
}
```

### Run the parameters validation

The `check_params.py` script is used to validate the calibration parameters. As explained in the Parameters Validation section, it performs a Jacobian invertibility test and a bounds test.

To run the validation execute the `check_params.py` script:

```bash
python check_params.py
```

The script accepts the following parameters to customize the joints and axes bounds:

- `--axis-min`: The minimum value of the X, Y, and Z axes.
- `--axis-max`: The maximum value of the X, Y, and Z axes.
- `--joint-min`: The minimum value of the X, Y, and Z joints.
- `--joint-max`: The maximum value of the X, Y, and Z joints.

### LinuxCNC Configuration for the `calibxyzkins` module

The `calibxyzkins` module included in this repository can be used to calibrate the gantry robot with the correction parameters obtained from the calibration process. To use the module, its HAL parameters must be set properly. These parameters can be generated using the `print_calibxyzkins_config.py` script:

```bash
python print_calibxyzkins_config.py
```

Which will output the following HAL configuration:

```text
# Calibration matrix A
setp calibxyzkins.calib-a.xx 0.9990369633
setp calibxyzkins.calib-a.xy 0.00351911362
setp calibxyzkins.calib-a.xz 0.01233976766
setp calibxyzkins.calib-a.yx -0.002370503681
setp calibxyzkins.calib-a.yy 1.002465791
setp calibxyzkins.calib-a.yz 0.003979069254
setp calibxyzkins.calib-a.zx -0.001035471646
setp calibxyzkins.calib-a.zy -0.004752129099
setp calibxyzkins.calib-a.zz 1.000191446

# Calibration matrix B
setp calibxyzkins.calib-b.xx 2.205888871e-07
setp calibxyzkins.calib-b.xy -8.883515393e-07
setp calibxyzkins.calib-b.xz 0
setp calibxyzkins.calib-b.yx 3.1221182e-07
setp calibxyzkins.calib-b.yy -4.690445432e-08
setp calibxyzkins.calib-b.yz 0
setp calibxyzkins.calib-b.zx 2.301649573e-07
setp calibxyzkins.calib-b.zy 9.733292478e-07
setp calibxyzkins.calib-b.zz 0

# Calibration vector C
setp calibxyzkins.calib-c.x 9.648396195
setp calibxyzkins.calib-c.y 0.8905471887
setp calibxyzkins.calib-c.z 4.55518685
```

### Gantry and Calibrated OptiTrack Path Visualization

The gantry and calibrated OptiTrack path can be visualized using the `plot_movement.py` script:

```bash
python ../../src/plot_movement.py
```

Note that the script accepts the `--no-correct` flag to show the OptiTrack position without applying the correction transformation.

The image below shows the gantry and calibrated OptiTrack path visualization.

Gantry and calibrated OptiTrack path visualization

As in the case of the raw data visualization scripts, you can use the keyboard to control the playback of the data. The available controls are shown when the script is executed:

```text
Animation Controls:
------------------
Space: Play/Pause
PageUp/PageDown: Increase/Decrease playback speed
Shift + PageUp/PageDown: Increase/Decrease playback speed by 5x
m/n: Step forward/backward 1 frame
M/N: Step forward/backward 60 frames
Ctrl+m/Ctrl+n: Step forward/backward 600 frames
i/o: Jump to start/end
```

### Plot Positioning Errors Over Time

The positioning errors between gantry and OptiTrack data over time can be plotted using the `plot_errors.py` script:

```bash
python ../../src/plot_errors.py
```

The script accepts the option `--time-unit` to specify the time unit of the x-axis. The available options are `s` (seconds) and `frames`. The default is `s` (seconds). The `frames` options can be used to check the ranges of frames with poor tracking quality, then they can be skipped by setting them in the configuration file.

The script also accepts the `--no-correct` flag to show the OptiTrack position without applying the correction transformation.

The image below shows the positioning errors over time with the `--no-correct` flag, i.e., without applying the correction transformation to the OptiTrack position.

Positioning errors over time

The image below shows the positioning errors over time when applying the correction transformation to the OptiTrack position.

Positioning errors over time

### Plot Positioning Errors Scatter

Positioning errors scatter plots between gantry and OptiTrack data can be plotted using the `plot_errors_scatter.py` script:

```bash
python ../../src/plot_errors_scatter.py
```

The script also accepts the `--no-correct` flag to show the OptiTrack position without applying the correction transformation.

The image below shows the positioning errors scatter plots with the `--no-correct` flag, i.e., without applying the correction transformation to the OptiTrack position.

Positioning errors scatter plots

The image below shows the positioning errors scatter plots when applying the correction transformation to the OptiTrack position.

Positioning errors scatter plots

### Plot Positioning Errors Probability Distributions

The positioning errors probability distribution can be plotted using the `plot_errors_probability.py` script:

```bash
python ../../src/plot_errors_probability.py
```

By default the script plots the probability distribution of the positioning errors for the x, y, and z axes. The image below shows the obtained probability distributions.

Positioning errors probability distributions

The script accepts the `--cumulative` flag to plot the cumulative distribution function of the positioning errors. The image below shows the cumulative distribution function of the positioning errors for the x, y, and z axes.

Positioning errors cumulative distribution function

## License

See the LICENSE file for details.

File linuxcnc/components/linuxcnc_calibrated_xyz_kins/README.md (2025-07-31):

# calibxyzkins - Calibrated XYZ Kinematics for LinuxCNC

A LinuxCNC kinematics module that provides coordinate transformations for cartesian machines to correct minor structural deviations and positioning errors.

## Overview

The `calibxyzkins` module extends the standard trivial kinematics by applying a mathematical correction to compensate for systematic positioning errors in gantry robots and similar cartesian machines. This is particularly useful for correcting:

- Mechanical inaccuracies in manufacturing or assembly
- Structural deformations under load
- Non-perpendicular axes alignment
- Position-dependent errors

## Coordinate Transformation

The module implements a coordinate transformation that corrects the relationship between joint positions and actual machine coordinates using both linear and quadratic terms:

$[x', y', z']^T = A [x, y, z]^T + B [x^2, y^2, z^2]^T + C$

Where:

- $(\cdot)^T$: Transpose operator
- $A$: 3×3 linear transformation matrix (scaling, rotation, shear, etc.)
- $B$: 3×3 quadratic transformation matrix (corrects non-linear distortions)
- $C$: 3×1 offset vector (constant position offset)
- $x, y, z$: joint positions
- $x', y', z'$: axes coordinates

The default values of the parameters are:

- $A$: 3x3 identity matrix
- $B$: all zeros
- $C$: all zeros

## Installation

### Prerequisites

- LinuxCNC development environment
- Standard build tools (make, gcc)

### Building

To build the module, run:

```bash
cd linuxcnc/components/linuxcnc_calibrated_xyz_kins
make
```

To install the module system-wide, run:

```bash
sudo make install
```

### Loading the Module

The module can be loaded as any other HAL component. Depending on the machine configuration, the `coordinates` and `kinstype` parameters can be used to specify the axis-to-joint mapping.

Examples:

- Basic usage (equivalent to `trivkins`):

  ```hal
  loadrt calibxyzkins
  ```

- Specify coordinate mapping:

  ```hal
  loadrt calibxyzkins coordinates=xyz
  ```

- Gantry configuration with duplicated Y axis:

  ```hal
  loadrt calibxyzkins coordinates=xyyz kinstype=B
  ```

## Module Parameters

### `coordinates`

Specifies the axis-to-joint mapping, as in `trivkins`:

- **coordinates=xyz**: Standard 3-axis mapping (X→joint0, Y→joint1, Z→joint2)
- **coordinates=xyyz**: Gantry with dual Y motors (X→joint0, Y→joint1&joint2, Z→joint3)
- **coordinates=xyzabc**: 6-axis machine. Note that calibration is only applied to the X, Y, and Z axes.

### `kinstype`

Specifies the kinematics type, as in `trivkins`:

- **kinstype=1**: KINEMATICS_IDENTITY (default)
- **kinstype=B**: KINEMATICS_BOTH
- **kinstype=F**: KINEMATICS_FORWARD_ONLY
- **kinstype=I**: KINEMATICS_INVERSE_ONLY

## HAL Parameters

### Calibration Matrix A (Linear Terms)

- `calibxyzkins.calib-a.xx` (float, RW, default: 1.0)
- `calibxyzkins.calib-a.xy` (float, RW, default: 0.0)
- `calibxyzkins.calib-a.xz` (float, RW, default: 0.0)
- `calibxyzkins.calib-a.yx` (float, RW, default: 0.0)
- `calibxyzkins.calib-a.yy` (float, RW, default: 1.0)
- `calibxyzkins.calib-a.yz` (float, RW, default: 0.0)
- `calibxyzkins.calib-a.zx` (float, RW, default: 0.0)
- `calibxyzkins.calib-a.zy` (float, RW, default: 0.0)
- `calibxyzkins.calib-a.zz` (float, RW, default: 1.0)

### Calibration Matrix B (Quadratic Terms)

- `calibxyzkins.calib-b.xx` (float, RW, default: 0.0)
- `calibxyzkins.calib-b.xy` (float, RW, default: 0.0)
- `calibxyzkins.calib-b.xz` (float, RW, default: 0.0)
- `calibxyzkins.calib-b.yx` (float, RW, default: 0.0)
- `calibxyzkins.calib-b.yy` (float, RW, default: 0.0)
- `calibxyzkins.calib-b.yz` (float, RW, default: 0.0)
- `calibxyzkins.calib-b.zx` (float, RW, default: 0.0)
- `calibxyzkins.calib-b.zy` (float, RW, default: 0.0)
- `calibxyzkins.calib-b.zz` (float, RW, default: 0.0)

### Calibration Vector C (Offset Terms)

- `calibxyzkins.calib-c.x` (float, RW, default: 0.0)
- `calibxyzkins.calib-c.y` (float, RW, default: 0.0)
- `calibxyzkins.calib-c.z` (float, RW, default: 0.0)

### Joint Limits

- `calibxyzkins.min-limit.x` (float, RW, default: -∞)
- `calibxyzkins.min-limit.y` (float, RW, default: -∞)
- `calibxyzkins.min-limit.z` (float, RW, default: -∞)
- `calibxyzkins.max-limit.x` (float, RW, default: +∞)
- `calibxyzkins.max-limit.y` (float, RW, default: +∞)
- `calibxyzkins.max-limit.z` (float, RW, default: +∞)

## HAL Pins

### Inverse Kinematics Solver Settings

- `calibxyzkins.max-iter` (u32, IO, default: 10)
  - Maximum number of Newton-Raphson iterations for the inverse kinematics.
- `calibxyzkins.tol` (float, IO, default: 1e-3)
  - Convergence tolerance for the inverse kinematics solver.

## Inverse Kinematics

The module uses the Newton-Raphson method to solve the inverse kinematics problem iteratively:

1. Initialize joint positions (bounded by joint limits if specified)
2. Compute function: F = A \* joints + B \* joints^2 + C - target_position
3. Compute Jacobian: J = A + 2 \* B \* diag(joints)
4. Update joints: joints = joints - J^-1 \* F
5. Repeat until convergence (||F|| < tolerance) or max iterations reached.

## Debugging

Verbose output of the inverse kinematics solver can be enabled by compiling the code with the `CALIB_XYZ_INVERSE_PRINT_ITER` macro defined.

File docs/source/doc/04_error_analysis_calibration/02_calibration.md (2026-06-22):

# Data and Calibration

(sec:data_format)=

## Data Format

The calibration system requires data from both the gantry robot and the OptiTrack motion capture system in specific CSV formats.

### Gantry Data (CSV)

The gantry data is a CSV file with the following columns:

- `time` - Unix time (seconds since 1970-01-01 00:00:00 UTC) as a floating-point number.
- `x`, `y`, `z` - Position coordinates in mm as floating-point numbers.

### OptiTrack Data (CSV)

The OptiTrack data is the CSV exported from the OptiTrack Motive software. The format follows this structure:

- **Line 1**: Header with metadata (format version, take name, capture frame rate, export frame rate, start time, total frames, rotation type, length units, coordinate space, etc.)
- **Line 2**: Blank line
- **Line 3**: Object types for each column (e.g., "Rigid Body", "Rigid Body Marker", "Marker")
- **Line 4**: Object names for each column (e.g., "Grua", "Grua:Marker1", "Active 1", "Unlabeled 1007")
- **Line 5**: Unique object IDs (hexadecimal identifiers for each marker/object)
- **Line 6**: Data types for each column ("Rotation" or "Position")
- **Line 7**: Column headers ("Frame", "Time (Seconds)", "X", "Y", "Z", "W" for quaternion rotation, then "X", "Y", "Z" for position coordinates)
- **Line 8 onwards**: Data rows containing:
  - Frame number (integer)
  - Time in seconds (floating-point)
  - Rotation and/or position coordinates.

:::{note}
Missing or untracked data points appear as empty cells in the CSV.
:::

## Calibration Process

The calibration process performs two steps: alignment and correction.

### Alignment

First, the OptiTrack data must be aligned with the gantry data to account for differences in coordinate systems and timing. This alignment process involves finding the following parameters:

- **Translation**: Shifts in X, Y, and Z axes
- **Rotation**: Rotations around X, Y, and Z axes. By default the rotation center is `(2500, 2500, -750)`, but it may be changed.
- **Time Shift**: Temporal alignment to account for timing differences.

The alignment parameters are found using numerical optimization, with the Powell method by default, to minimize the mean squared error between gantry and the aligned OptiTrack positions. The optimization is performed using the `scipy.optimize.minimize` function.

### Correction

Analysis of scatter plots of the positioning errors (see {numref}`sec:plot_errors_scatter`) reveals clear patterns in positioning errors:

- **Y-axis position affects errors in all axes**
- **X-axis position affects errors in the Y-axis**
- **Z-axis position affects errors in X and Y axes**

These systematic deviations can be corrected by applying a coordinate transformation when controlling the gantry robot. For this we consider a general coordinate transformation with both first-order and second-order components:

$$
\begin{bmatrix}
x' \\ y' \\ z'
\end{bmatrix} =
\underbrace{
\begin{bmatrix}
a_{11} & a_{12} & a_{13} \\ a_{21} & a_{22} & a_{23} \\ a_{31} & a_{32} & a_{33}
\end{bmatrix}
}_{\normalsize \mathbf{A}}
\begin{bmatrix}
x \\ y \\ z
\end{bmatrix} +
\underbrace{
\begin{bmatrix}
b_{11} & b_{12} & 0 \\ b_{21} & b_{22} & 0 \\ b_{31} & b_{32} & 0
\end{bmatrix}
}_{\normalsize \mathbf{B}}
\begin{bmatrix}
x^2 \\ y^2 \\ z^2
\end{bmatrix} +
\underbrace{
\begin{bmatrix}
c_1 \\ c_2 \\ c_3
\end{bmatrix}
}_{\normalsize \mathbf{c}}
$$

where $x, y, z$ are the aligned OptiTrack position coordinates (the actual position of the gantry robot), $x', y', z'$ are the corrected position coordinates (the target position for the gantry control), and $\mathbf{A}, \mathbf{B}, \mathbf{c}$ are the transformation matrices and vector that need to be optimized.

:::{note}
The third column of the second-order matrix $\mathbf{B}$ is set to zero because the Z-axis measurement interval is small, making the $z^2$ term unreliable if $z$ is extrapolated.
:::

This transformation consists of:

1. Matrix $\mathbf{A}$: Linear transformation that handles scaling, rotation, and shear.
2. Matrix $\mathbf{B}$: Quadratic transformation that corrects non-linear distortions.
3. Vector $\mathbf{c}$: Constant offset.

The correction parameters are found using numerical optimization, with the Powell method by default, to minimize the mean squared error between gantry and the corrected OptiTrack positions. The optimization is performed using the `scipy.optimize.minimize` function.

## Parameters Validation

The `calibxyzkins` module of LinuxCNC included in this project uses the Newton-Raphson algorithm to solve the inverse kinematics problem: given desired axes positions $x', y', z'$, it finds the corresponding joint positions $x, y, z$ that satisfy the transformation equation:

$$\mathbf{f}(x, y, z) = \mathbf{A} \begin{bmatrix} x \\ y \\ z \end{bmatrix} + \mathbf{B} \begin{bmatrix} x^2 \\ y^2 \\ z^2 \end{bmatrix} + \mathbf{c} = \begin{bmatrix} x' \\ y' \\ z' \end{bmatrix}$$

To ensure the calibration parameters are valid we include the `check_params.py` script, which performs the following validation tests:

### Jacobian Invertibility Test

The Newton-Raphson method requires computing the Jacobian matrix of the transformation function:

$$\mathbf{J} = \frac{\partial \mathbf{f}}{\partial \mathbf{x}} = \mathbf{A} + 2 \cdot \mathbf{B} \cdot \text{diag}(x, y, z)$$

where $\mathbf{x} = [x, y, z]^T$ and $\frac{\partial \mathbf{f}}{\partial \mathbf{x}}$ denotes the Jacobian matrix with entries $J_{ij} = \partial f_i / \partial x_j$.

The Jacobian matrix must be invertible throughout the robot's workspace. This is tested using an approach based on the Neumann series.

The Neumann series states that $(\mathbf{I} - \mathbf{T})$ is invertible if $\|\mathbf{T}\| < 1$, where $\mathbf{I}$ is the identity matrix and $\|\cdot\|$ denotes a matrix norm.

For a matrix of the form $\mathbf{X} + \mathbf{Y} = \mathbf{X}(\mathbf{I} + \mathbf{X}^{-1}\mathbf{Y})$, the matrix has an inverse if $\|\mathbf{X}^{-1}\mathbf{Y}\| < 1$.

Applying this to our Jacobian:

- $\mathbf{X} = \mathbf{A}$
- $\mathbf{Y} = 2 \cdot \mathbf{B} \cdot \text{diag}(x, y, z)$

Therefore, the Jacobian $\mathbf{J}$ is invertible if $\mathbf{A}$ is invertible and $\|2 \cdot \mathbf{A}^{-1} \cdot \mathbf{B} \cdot \text{diag}(x, y, z)\| < 1$ for the maximum absolute values of $x, y, z$ in the joint space bounds.

This condition is checked in the `check_params.py` script using both the 1-norm and infinity-norm.

### Bounds Test

The coordinate transformation must respect the physical limits of the robot, i.e., the desired axes positions $(x', y', z')$ must be within the robot's axes limits, and the corresponding joint positions $(x, y, z)$ computed by the inverse kinematics must be within the robot's joint limits.

This condition is checked in the `check_params.py` script by finding the minimum and maximum values that each joint can reach when the axes positions are constrained to their limits. These values must fall within the specified joint limits of the robot for the parameters to be valid.

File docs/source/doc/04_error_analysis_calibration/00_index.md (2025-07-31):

(sec:error_analysis_calibration)=

# Error Analysis and Calibration

The gantry robot system includes a calibration solution that leverages an existing [OptiTrack](https://optitrack.com/) motion capture system to measure and compensate for systematic positioning errors caused by minor structural deviations in the robot. This calibration system enables the gantry robot to achieve sub-centimeter precision across its entire work envelope.

:::{important}
It is assumed that the gantry data is the commanded position of the gantry robot and the OptiTrack data is the actual position of the gantry robot. After the calibration is complete it can be evaluated with several scripts, which correct the OptiTrack data with the calibration parameters and compare the obtained positions with the reference gantry data.
:::

The error analysis and calibration system consists of several scripts to process and analyze the data collected from both the gantry robot and the OptiTrack motion capture system:

1. **Raw Data Visualization**: `plot_movement_gantry.py` and `plot_movement_optitrack.py` scripts to visualize the raw gantry and OptiTrack data before calibration.

2. **Calibration**: `run_calibration.py` is the script that processes the raw data, performing the following steps:
   - **Alignment**: Temporal and spatial alignment of OptiTrack and gantry robot coordinate systems using translation, rotation, and time shift transformations.
   - **Correction**: Non-orthogonal and non-linear transformation of the OptiTrack data to correct errors intrinsic to the gantry robot.

3. **Analysis**: Various scripts for plotting and analyzing the gantry and OptiTrack data, which can be executed after the calibration is complete:
   - `check_params.py`: Check the calibration parameters.
   - `print_calibxyzkins_config.py`: Print the HAL configuration for the `calibxyzkins` module.
   - `plot_movement.py`: Visualize the gantry and OptiTrack path.
   - `plot_errors.py`: Plot positioning errors over time.
   - `plot_errors_scatter.py`: Plot positioning errors scatter plots.
   - `plot_errors_probability.py`: Plot positioning errors probability distributions.

After the calibration is performed, the calibration parameters can be used to correct the gantry position data with the `calibxyzkins` module of LinuxCNC included in this project (see {ref}`sec:calibxyzkins_module`).

:::{toctree}
:maxdepth: 2
:caption: Table of Contents

01_installation.md
02_calibration.md
03_usage.md
:::

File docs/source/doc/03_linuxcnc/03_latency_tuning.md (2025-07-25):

# System Latency Tuning

The maximum system latency can depend on various factors such as hardware, firmware configuration, system load, and hardware interrupt handling. If the maximum system latency is too high, adjustments to the system configuration will be necessary to reduce it. Various sources, including official documentation, guides, and talks, provide detailed guidelines for optimizing the performance of real-time Linux systems {cite}`redhat_rt_low_latency,ubuntu_rt_tuning,lfoss2022tips,elc2023preparing`. The LinuxCNC user manual {cite}`linuxcncdoc` also suggests several potential adjustments to reduce latency, which are detailed in {numref}`sec:firmware_settings` and {numref}`sec:linux_settings`.

For our gantry robot setup, we used a Beelink EQR6 mini computer equipped with an AMD Ryzen 5 6600U CPU. In our case, latency values were sufficiently low, similar to the ones shown in {numref}`fig:linuxcnc_latency_plot`, {numref}`fig:linuxcnc_latency_test`, and {numref}`fig:linuxcnc_latency_histogram`. However, note that for other hardware, even with the same operating system, the latency values could be higher. If the system latency becomes too high during LinuxCNC operation, a warning similar to {numref}`fig:linuxcnc_gui_axis_delay_warning` would appear. In that case check {numref}`sec:firmware_settings` and {numref}`sec:linux_settings` for potential solutions.

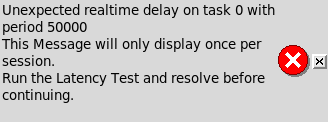
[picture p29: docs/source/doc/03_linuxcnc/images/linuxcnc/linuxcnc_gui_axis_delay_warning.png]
:::{figure} images/linuxcnc/linuxcnc_gui_axis_delay_warning.png
:name: fig:linuxcnc_gui_axis_delay_warning

LinuxCNC warning for unexpected latency values.
:::

While our system latency measurements were within acceptable ranges, we encountered a high network latency problem on the LinuxCNC communication with the MESA 7I96S via Ethernet. This issue was resolved by replacing the open-source Realtek driver with the official closed-source Realtek driver as explained in {numref}`sec:network_latency_issues`.

(sec:firmware_settings)=

## Firmware Settings

System firmware such as the {{BIOS}} or {{UEFI}}, can significantly impact system latency. This impact varies depending on the hardware manufacturer and the quality of the provided firmware. Firmware is responsible for initializing and configuring system hardware before the operating system loads. If the firmware is not properly configured to provide accurate timing or does not adequately manage interrupts and hardware devices, it can contribute to increased system latency.

The firmware settings recommended in the LinuxCNC user manual {cite}`linuxcncdoc` that can help reduce latency include the following:

- Disable {{APM}}, {{ACPI}}, and other power-saving functions, including all suspension related features and CPU frequency scaling.
- Disable CPU "turbo" mode.
- Disable CPU simultaneous multithreading technology, e.g., Intel's Hyper-Threading technology.
- Disable or limit SMIs (System Management Interrupts).
- Disable unused hardware.

(sec:linux_settings)=

## Linux Settings

Linux offers various options that can help improve latency. Specifically, for our case, we will consider kernel boot command-line parameters and runtime parameters configured via the `sysctl` command. These parameters are described below.

### Kernel Boot Command-Line Parameters

A comprehensive list of parameters is available at <https://docs.kernel.org/admin-guide/kernel-parameters.html>. In Debian, command-line parameters can be specified in the following ways:

1. In the GRUB bootloader, you can press a key (often {kbd}`e`) to edit the selected boot entry and append the parameters to the end of the line. Once added, you can boot the system by pressing {kbd}`F10` or {kbd}`Ctrl+X`.
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

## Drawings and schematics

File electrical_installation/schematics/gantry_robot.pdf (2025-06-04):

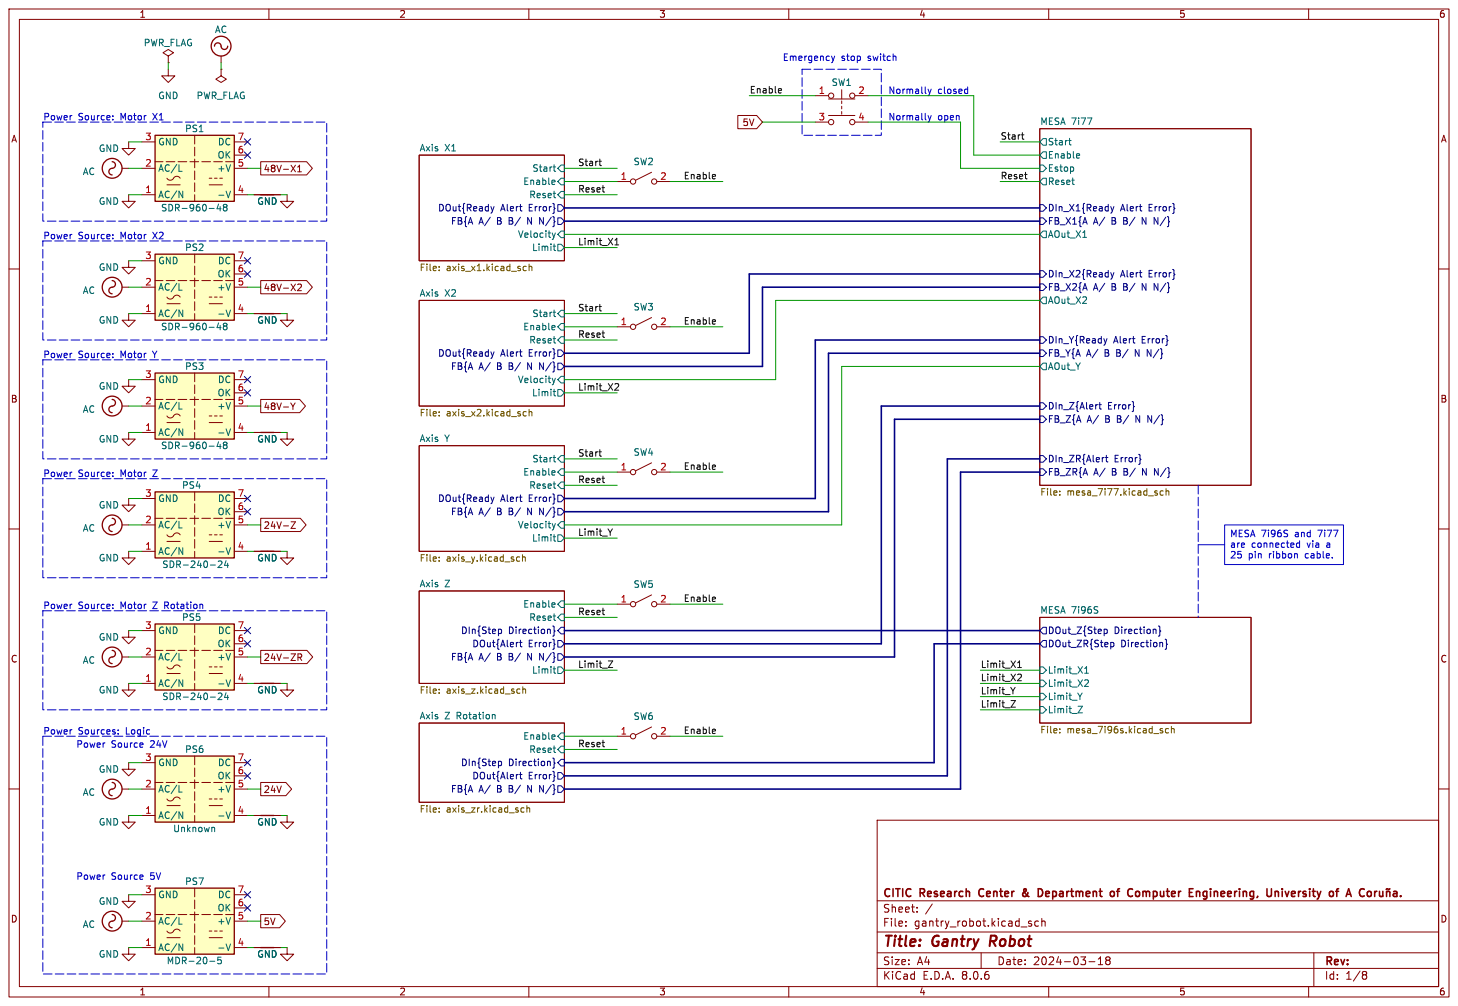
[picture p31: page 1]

-V 4 +V 5 OK 6 DC 7 PS2 SDR-960-48 PWR_FLAG
-V 4 +V 5 OK 6 DC 7 PS1 SDR-960-48 AC/N 1 AC/L 2 GND 3
AC/N 1 AC/L 2 GND 3
-V 4 +V 5 OK 6 DC 7 PS4 SDR-240-24 GND
Power Source: Motor Z Rotation Power Source: Motor Z Power Source: Motor X2 Power Source 24V

Velocity Start Reset Axis X1 File: axis_x1.kicad_sch

-V 4 +V 5 OK 6 DC 7 PS3 SDR-960-48 AC

Limit DOut{Ready Alert Error} Enable FB{A A/ B B/ N N/}

Velocity Limit Enable Start Reset Axis X2 File: axis_x2.kicad_sch

25 pin ribbon cable. GND GND GND GND

Velocity Enable Start Reset Axis Y

Limit DOut{Ready Alert Error}

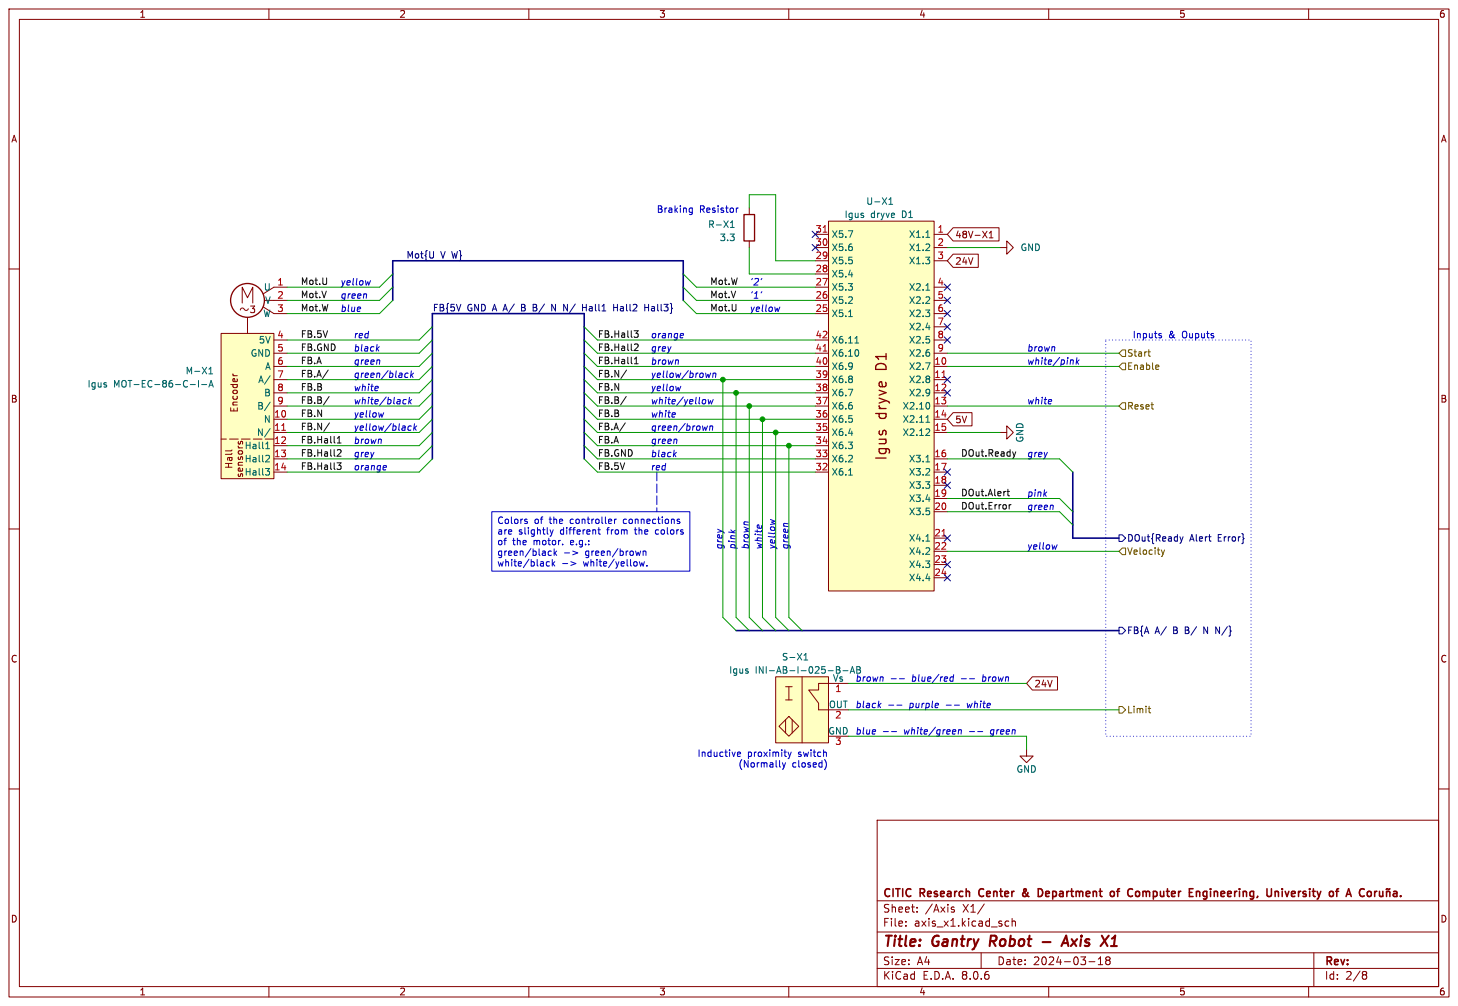
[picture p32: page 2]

DOut{Ready Alert Error} Start Enable Reset Limit FB{A A/ B B/ N N/}

Id: 2/8 Title: Gantry Robot - Axis X1

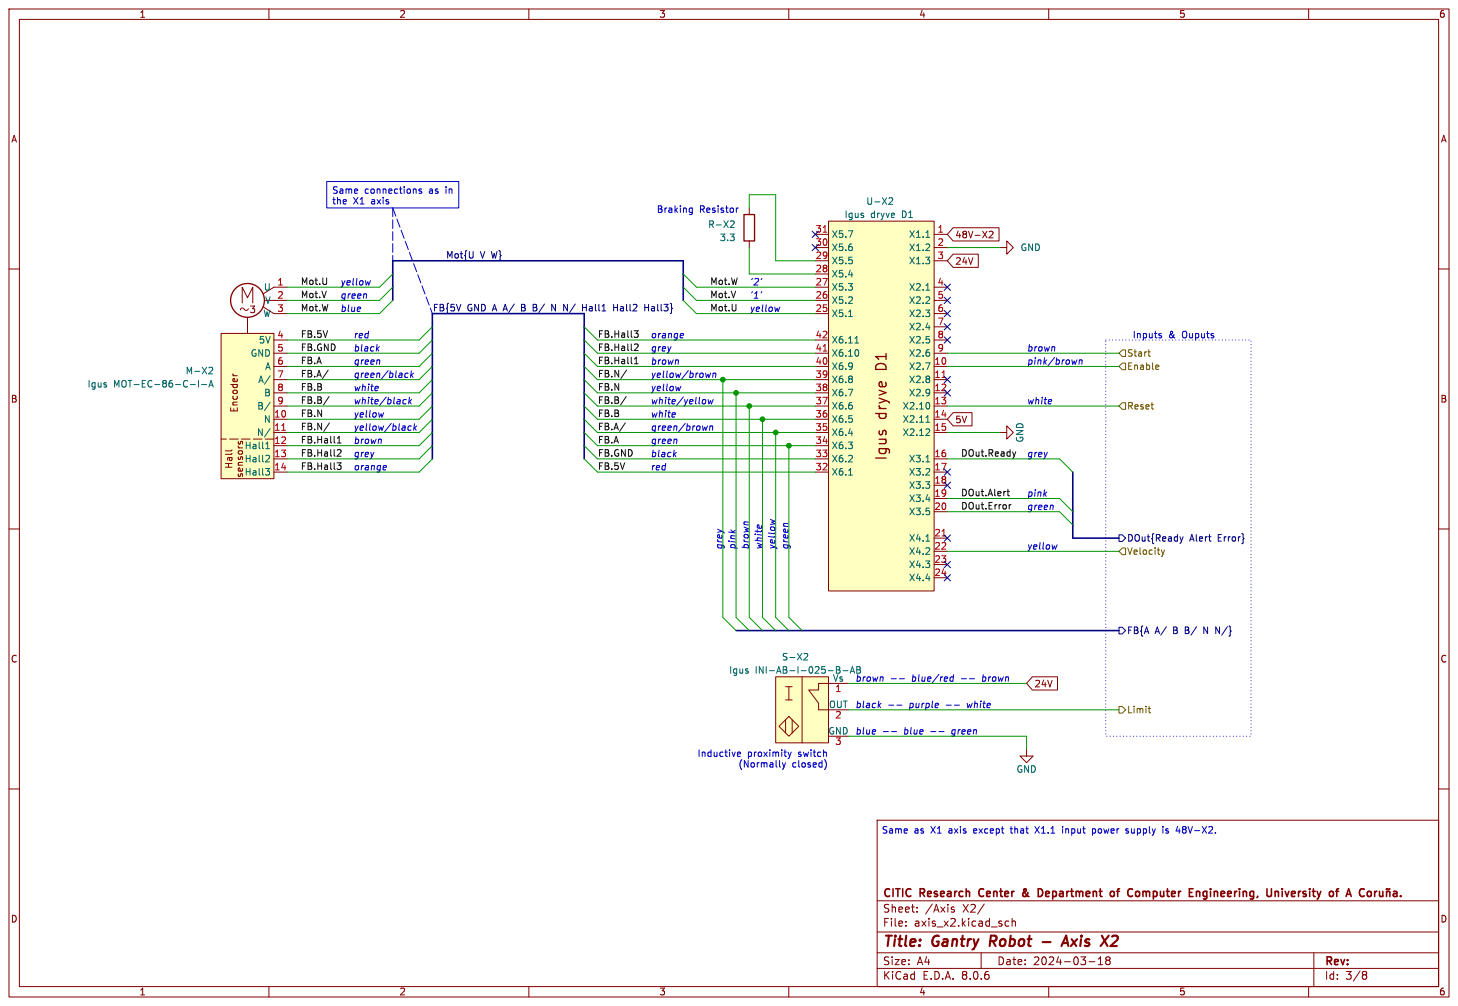
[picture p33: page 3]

Braking Resistor grey pink orange
Igus INI-AB-I-025-B-AB R-X2

FB.A Mot.U Mot.V Mot.W
3 Encoder Hall

'2' grey white/yellow
'1' yellow/brown
FB.Hall3 FB.Hall1 FB.Hall2 FB.A

red
Inputs & Ouputs brown white/black

Id: 3/8 Title: Gantry Robot - Axis X2

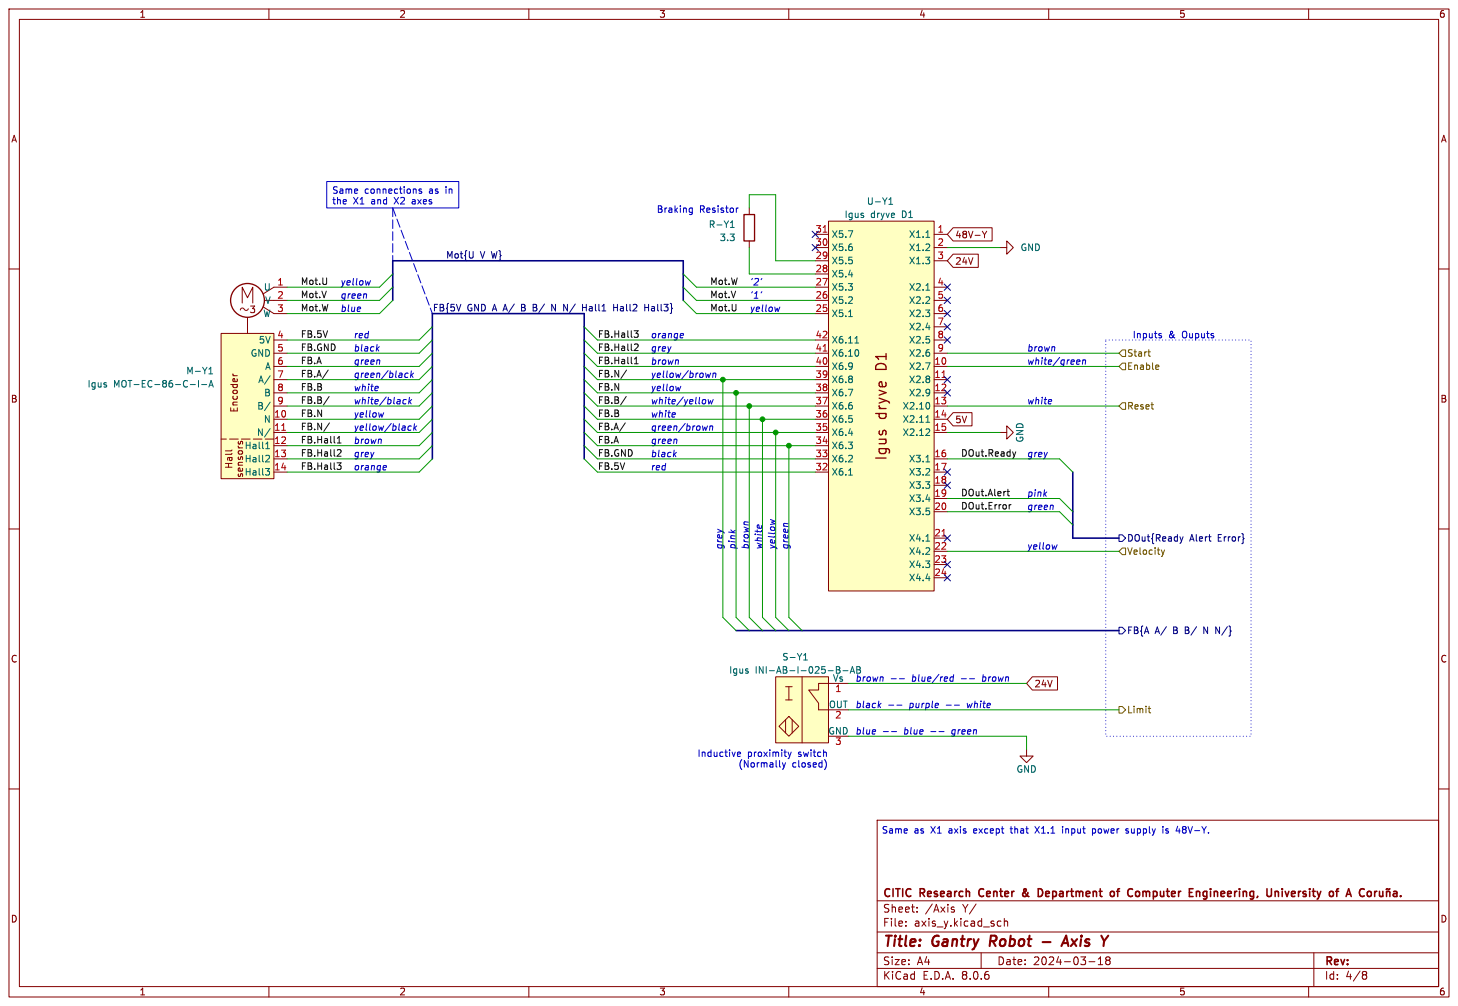
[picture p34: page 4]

Enable Reset Start DOut{Ready Alert Error}

Igus INI-AB-I-025-B-AB

Id: 4/8 Title: Gantry Robot - Axis Y

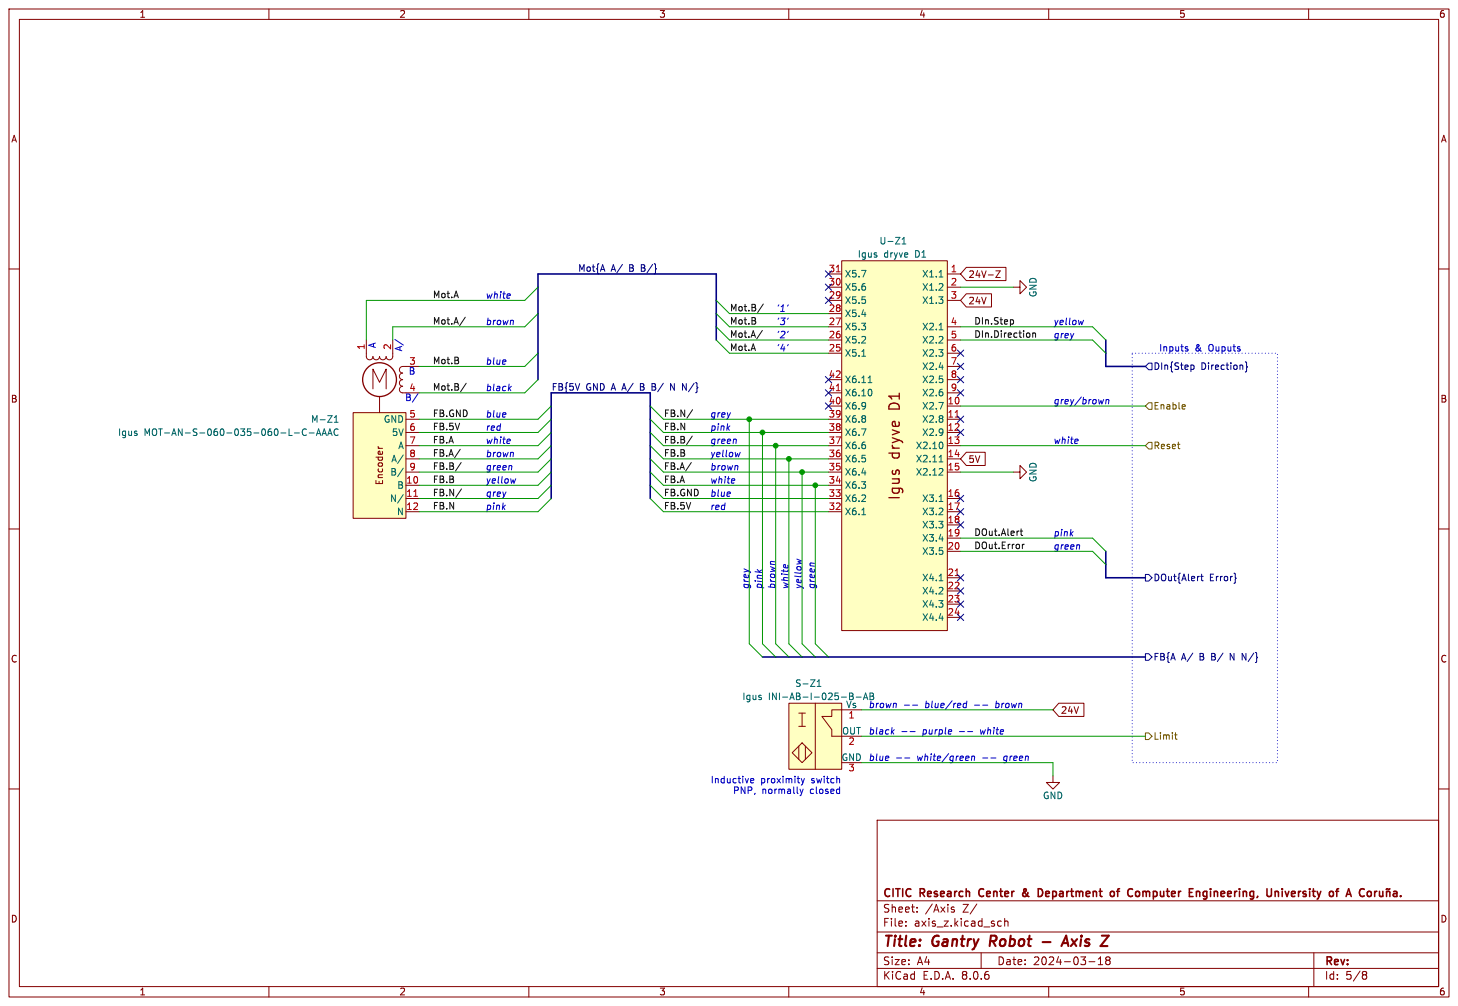
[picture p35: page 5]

Id: 5/8 Title: Gantry Robot - Axis Z

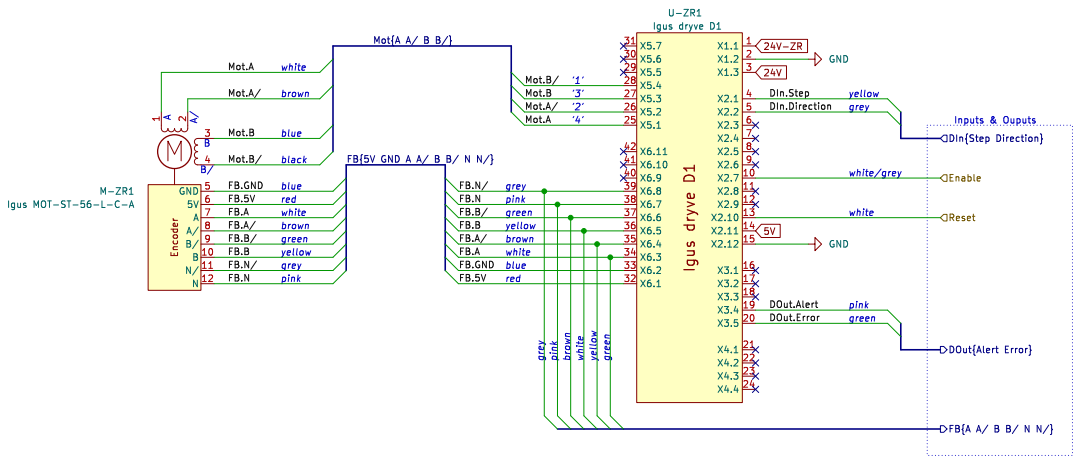
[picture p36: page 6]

FB{5V GND A A/ B B/ N N/} FB.A Mot.B

Id: 6/8 Title: Gantry Robot - Axis Z Rotation

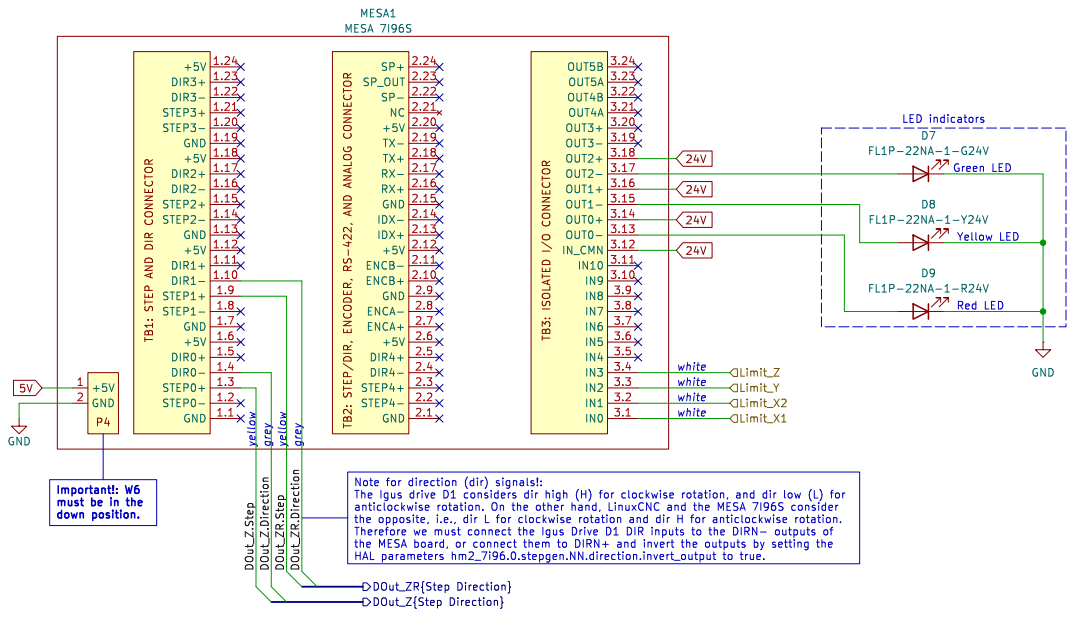
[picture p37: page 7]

LED indicators Red LED

Id: 7/8 Title: Gantry Robot - MESA 7I96S

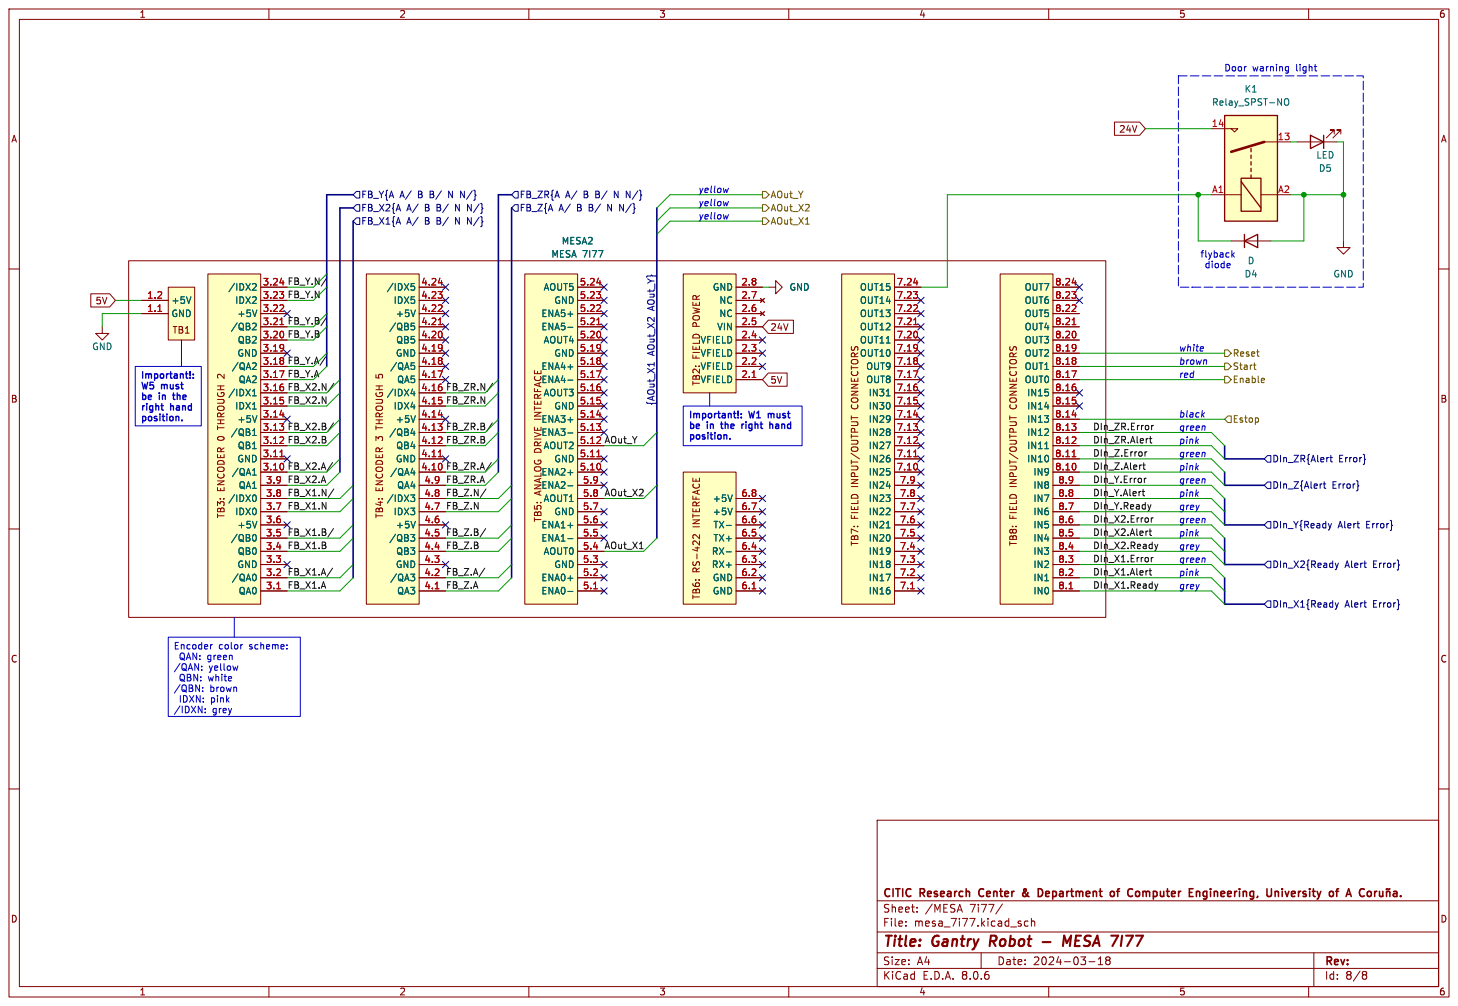
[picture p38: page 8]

Door warning light green

Important!: W5 must be in the

right hand
position.Encoder color scheme: QAN: green

Important!: W1 must be in the right hand

/QAN: yellow QBN: white

Id: 8/8 Title: Gantry Robot - MESA 7I77

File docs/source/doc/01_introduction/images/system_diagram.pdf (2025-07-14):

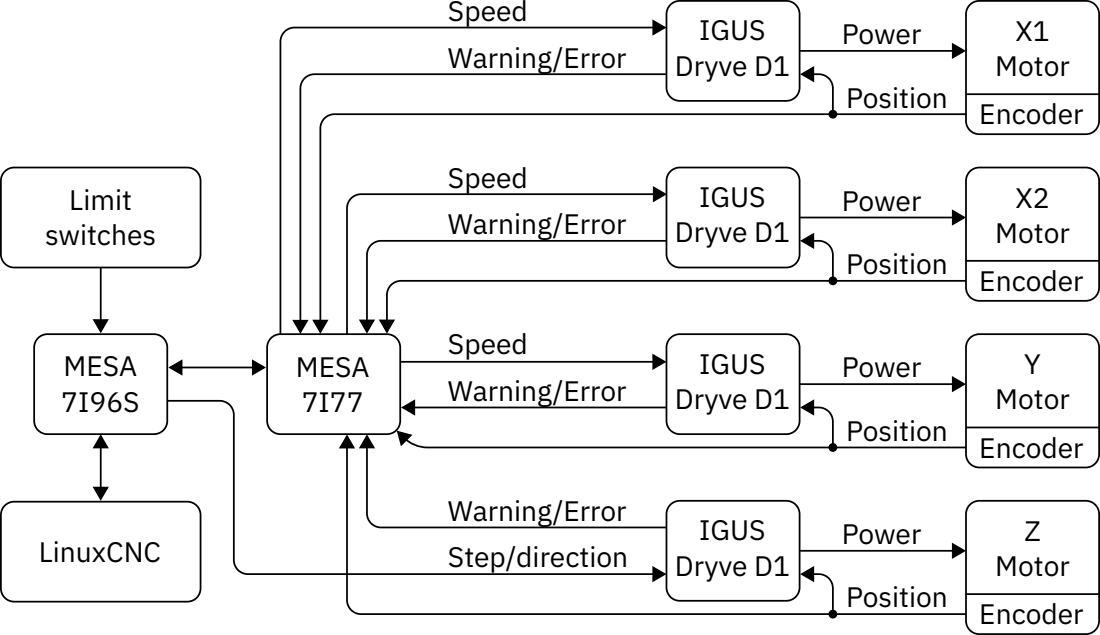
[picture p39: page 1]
Limit switches; MESA 7I96S; MESA 7I77; IGUS Dryve D1; Speed Warning/Error; X1 Motor Encoder; X2 Motor Encoder Y; Motor Encoder Z; Motor Encoder; Power; Position; Speed; Warning/Error; LinuxCNC; Step/direction

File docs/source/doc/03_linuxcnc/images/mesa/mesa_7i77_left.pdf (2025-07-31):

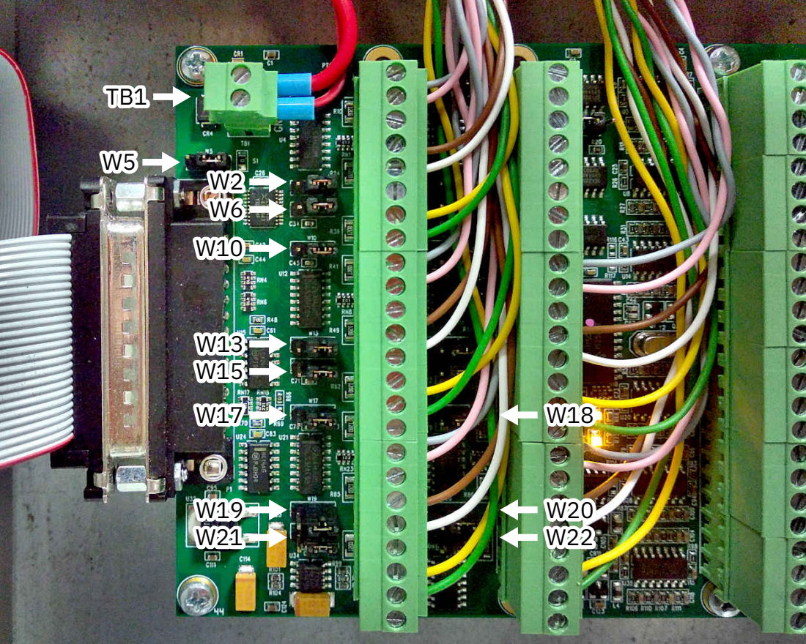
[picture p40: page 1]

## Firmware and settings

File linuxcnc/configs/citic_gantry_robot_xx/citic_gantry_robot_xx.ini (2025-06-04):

[EMC]
# Configuración general

# Nombre de la máquina, puede ser el que se quiera.
# Normalmente se mostrará en la ventana de la interfaz.
MACHINE = mesa_7i96s

# Flags de debug, con 0 no se imprimirán mensajes de debug.
DEBUG = 0

# Versión de la configuración, para LinuxCNC 2.9 debe ser 1.1.
VERSION = 1.1

[DISPLAY]
# Configuración de la interfaz gráfica

# Tipo de interfaz gráfica a usar.
DISPLAY = axis

# Systema de coordenadas: RELATIVE o MACHINE.
POSITION_OFFSET = MACHINE

# Coordenadas a mostrar: COMMANDED o ACTUAL.
POSITION_FEEDBACK = ACTUAL

# Máximo «feed override». Un «feed override» de 2 significa
# el 200% del «feed rate» programado.
MAX_FEED_OVERRIDE = 2.000000

# Imagen para mostrar en la pantalla de bienvenida.
INTRO_GRAPHIC = linuxcnc.gif

# Tiempo máximo en segundos de la pantalla de bienvenida.
INTRO_TIME = 5

# Directorio por defecto para los programas de G-code.
PROGRAM_PREFIX = /home/gtec/linuxcnc/nc_files

# Incrementos para mover el robot con el control manual.
INCREMENTS = 5mm 1mm .5mm .1mm .05mm .01mm .005mm

# El valor de coordenadas que se mostrará: COMMANDED o ACTUAL
POSITION_FEEDBACK = ACTUAL

# Velocidad lineal predeterminada con el control manual.
DEFAULT_LINEAR_VELOCITY = 1.000000

# Velocidad lineal máxima permitida con el control manual.
MAX_LINEAR_VELOCITY = 600.000000

# Velocidad lineal mínima permitida con el control manual.
MIN_LINEAR_VELOCITY = 0.000000

# Editor de texto a usar al clicar en File -> Edit.
EDITOR = mousepad

# Geometría de la vista 3D de la ventana de previsualización.
GEOMETRY = X

# Tiempo de actualización en milisegundos.
CYCLE_TIME = 100

# Archivo a abrir al iniciar LinuxCNC (opcional).
OPEN_FILE = ""

[TASK]
# Configuración del controlador de tareas

# Modulo controlador de tareas, milltask.
TASK = milltask

# Período de ejecución de milltask.
CYCLE_TIME = 0.010

[RS274NGC]
# Configuración del intérprete RS274NGC

# Archivo de variables del intérprete.
PARAMETER_FILE = linuxcnc.var

# Códigos de inicio para el intérprete.
RS274NGC_STARTUP_CODE = G21 G40 G90 G94 G97 G64 P0.025

[EMCMOT]
# Configuración del controlador de movimiento

# Módulo controlador de movimiento, motmod.
# No usado por LinuxCNC directamente, usado en el fichero HAL.
EMCMOT = motmod

# Número de segundos a esperar para que el modulo motion
# confirme la recepción de mensajes del modulo de tareas.
COMM_TIMEOUT = 1.0

# Período del hilo «servo»
# No usado por LinuxCNC directamente, usado en el fichero HAL.
SERVO_PERIOD = 1000000

[HAL]
# Configuración del Hardware Abstraction Layer (HAL)

# Añade los pines de la interfaz de usuario HAL.
HALUI = halui

# Archivo HAL a ejecutar al iniciar LinuxCNC.
# Puede especificarse multiples veces.
HALFILE = citic_gantry_robot_xx.hal

# Archivo HAL a ejecutar después de cargar la interfaz gráfica.
# POSTGUI_HALFILE = postgui.hal

# Archivo HAL a ejecutar al cerrar LinuxCNC.
# SHUTDOWN = shutdown.hal

[HALUI]
# Interfaz de usuario de HAL

# Comando MDI. Puede especificarse multiples veces.
# Para ejecutarlo usar el pin halui.mdi-command-NN,
# siendo NN el número de comando.
# MDI_COMMAND = G1 X0 Y0 Z0

[KINS]
# Cinemática

# Número de articulaciones (motores).
JOINTS = 2

# Módulo de cinemática
# No usado por LinuxCNC directamente, usado en el fichero HAL.
KINEMATICS = trivkins coordinates=XX kinstype=B

[APPLICATIONS]
# Aplicaciones adicionales. Puede especificarse multiples veces.
# APP=halscope 50000
APP=halscope 100000


[TRAJ]
# Configuración del planificador de trayectorias

# Ejes controlados. Valores posibles: X, Y, Z, A, B, C, U, V, W.
# Un eje se puede especificar más de una vez, e.g., XXYZ.
COORDINATES = XX

# Unidades para ejes lineales.
LINEAR_UNITS = mm

# Unidades para ejes rotatorios.
ANGULAR_UNITS = degree

# Velocidad lineal máxima, en unidades por segundo.
MAX_LINEAR_VELOCITY = 600.00

# Aceleración lineal máxima, en unidades por segundo^2.
MAX_LINEAR_ACCELERATION = 200.0

[EMCIO]
# Configuración del controlador de entrada/salida (I/O)

# Módulo controlador de la entrada/salida.
EMCIO = io

# Período al que se ejecutará EMCIO.
CYCLE_TIME = 0.100

[AXIS_X]
# Configuración del eje X

# Velocidad máxima del eje, en unidades por segundo.
MAX_VELOCITY = 600.0

# Aceleración máxima del eje, en unidades por segundo^2.
MAX_ACCELERATION = 200.0

# Límite mínimo para el eje, en unidades de la máquina.
MIN_LIMIT = -5.0

# Límite máximo para el eje, en unidades de la máquina.
MAX_LIMIT = 5500.0

[JOINT_0]
# Configuración del primer motor

# Tipo de motor, LINEAR o ANGULAR.
TYPE = LINEAR

# Error de seguimiento máximo, en unidades de la máquina.
FERROR = 50.0

# Error de seguimiento máximo a velocidades lentas.
MIN_FERROR = 50.0

# Velocidad máxima del motor, en unidades por segundo.
MAX_VELOCITY = 50.0

# Aceleración máxima del motor, en unidades por segundo^2.
MAX_ACCELERATION = 20.0

# Límite mínimo del motor, en unidades de la máquina.
MIN_LIMIT = -5.0

# Límite máximo del motor, en unidades de la máquina.
MAX_LIMIT = 5500.0

# Posición a la que se moverá la articulación al completar
# el proceso de referenciado (homing).
HOME = 0

# Usado para definir el orden del "homing".
HOME_SEQUENCE = 1

# Posición del interruptor de "home", en unidades de la máquina.
HOME_OFFSET = -10

# Vel. de busqueda inicial del "homing", en unidades por segundo.
HOME_SEARCH_VEL = -25

# Vel. de busqueda final del "homing", en unidades por segundo.
HOME_LATCH_VEL = -5

# Vel. final del "homing", en unidades por segundo.
HOME_FINAL_VEL = 10

# Ignorar los interruptores de límites durante el "homing".
# = YES si se usa el mismo interruptor para límites y homing.
HOME_IGNORE_LIMITS = YES

# El interruptor se comparte con otra articulación.
HOME_IS_SHARED = 0

# Usar el pulso "index" del encoder para el "homing".
HOME_USE_INDEX = NO

# ---------------------------------------------------
# Configuraciones personalizadas para el archivo HAL.
# ---------------------------------------------------

# *** Configuración de salida analógica de +-10V ***

# Velocidad máxima en unidades por segundo.
ANALOGOUT_MAXLIM = 720

# Velocidad mínima en unidades por segundo.
ANALOGOUT_MINLIM = -720


# Escala de la salida analógica. Vout = 10 * velocidad / ANALOGOUT_SCALE.
# Velocidad máxima en unidades por segundo que podrá alcanzar el motor.
# Importante: debe establecerse a la misma velocidad máxima configurada
# en el controlador del motor en la sección de drive profile.
#
# El motor del eje X (Igus MOT-EC-86-C-I-A) tiene una reductora de ratio 0.1
# y una velocidad máxima de 3000 rpm. El eje X se desplaza a 144mm/rev.
# Por tanto la velocidad máxima es: 3000 * 0.1 / 60 * 144 = 720.0 mm/s.
ANALOGOUT_SCALE = -720

# *** Configuración de encoder ***

##############
# IMPORTANTE 
#
# Tener en cuenta que por error el motor X1 tiene una reductora 1:5
# (ratio 0.2) en vez de 1:10 (ratio 0.1) como la del motor X2, esto
# Hace que las escala del encoder de X1 sea distinta
##############

# Escala del encoder. ENCODER_SCALE = cuentas / Posición.
# OLD: El motor del eje X1 (Igus MOT-EC-86-C-I-A) tiene una reductora de ratio 0.2
# y el eje X se desplaza a 144 mm/rev. Por tanto el motor desplaza el eje
# 144 * 0.2 = 28.8 mm/rev.
# El encoder del motor X es de 1000 ppr (4000 cpr).
# ENCODER_SCALE = 4000 / 28.8 = 138.88888888888889
# ENCODER_SCALE = 138.88888888888889

# Escala del encoder. ENCODER_SCALE = cuentas / Posición.
# El motor del eje X (Igus MOT-EC-86-C-I-A) tiene una reductora de ratio 0.1
# y el eje X se desplaza a 144 mm/rev. Por tanto el motor desplaza el eje
# 144 * 0.1 = 14.4 mm/rev.
# El encoder del motor X es de 1000 ppr (4000 cpr).
# ENCODER_SCALE = 4000 / 14.4 = 277.77777777777777
ENCODER_SCALE = -277.7778

# *** Configuración del controlador PID ***

P = 40
I = 5
D = 0
FF0 = 0
FF1 = 1
FF2 = 0.01
BIAS = 0
DEADBAND = 0
MAX_OUTPUT = 0

[JOINT_1]
# Configuración del segundo motor

# Tipo de motor, LINEAR o ANGULAR.
TYPE = LINEAR

# Error de seguimiento máximo, en unidades de la máquina.
FERROR = 50

# Error de seguimiento máximo a velocidades lentas.
MIN_FERROR = 50

# Velocidad máxima del motor, en unidades por segundo.
MAX_VELOCITY = 50.0

# Aceleración máxima del motor, en unidades por segundo^2.
MAX_ACCELERATION = 20.0

# Límite mínimo del motor, en unidades de la máquina.
MIN_LIMIT = -5.0

# Límite máximo del motor, en unidades de la máquina.
MAX_LIMIT = 5500.0

# Posición a la que se moverá la articulación al completar
# el proceso de referenciado (homing).
HOME = 0

# Usado para definir el orden del "homing".
# Negativo para indicar que el motor debe realizar el proceso de homing
# junto con el otro motor del eje. Para más detalles consultar el manual
# de LinuxCNC
HOME_SEQUENCE = -1

# Posición del interruptor de "home", en unidades de la máquina.
HOME_OFFSET = -10

# Vel. de busqueda inicial del "homing", en unidades por segundo.
HOME_SEARCH_VEL = -25

# Vel. de busqueda final del "homing", en unidades por segundo.
HOME_LATCH_VEL = -5
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

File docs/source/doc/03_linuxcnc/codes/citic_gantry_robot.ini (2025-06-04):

[EMC]
# General configuration

# Machine name, can be whatever you want.
# It will normally be displayed in the interface window.
MACHINE = CITIC Gantry Robot

# Debug flags, with 0 no debug messages will be printed.
DEBUG = 0

# Configuration version, for LinuxCNC 2.9 must be 1.1.
VERSION = 1.1


[DISPLAY]
# Graphical interface configuration

# Type of graphical interface to use.
DISPLAY = axis

# Coordinate system: RELATIVE or MACHINE.
POSITION_OFFSET = MACHINE

# Coordinates to display: COMMANDED or ACTUAL.
POSITION_FEEDBACK = ACTUAL

# Override the default cone/tool base size of .5 in the graphics display.
CONE_BASESIZE = 2.0

# Maximum feed override. A feed override of 2 means
# 200% of the programmed feed rate.
MAX_FEED_OVERRIDE = 2.000000

# Image to show on the welcome screen.
INTRO_GRAPHIC = linuxcnc.gif

# Maximum time in seconds for the welcome screen.
INTRO_TIME = 5

# Default directory for G-code programs.
PROGRAM_PREFIX = /home/gtec/linuxcnc/nc_files

# Increments for moving the robot with manual control.
INCREMENTS = 5mm 1mm .5mm .1mm .05mm .01mm .005mm

# The coordinate value that will be displayed: COMMANDED or ACTUAL
POSITION_FEEDBACK = ACTUAL

# Default linear velocity with manual control, in units per second.
DEFAULT_LINEAR_VELOCITY = 100.0

# Maximum linear velocity allowed with manual control, in units per second.
MAX_LINEAR_VELOCITY = 600.0

# Minimum linear velocity allowed with manual control, in units per second.
MIN_LINEAR_VELOCITY = 0.0

# Text editor to use when clicking File -> Edit.
EDITOR = mousepad

# 3D view geometry in the preview window.
GEOMETRY = XYZ

# Update time in milliseconds.
CYCLE_TIME = 100

# PyVCP panel description file
PYVCP = gui_panel.xml

# File to open when starting LinuxCNC (optional).
OPEN_FILE = ""


[TASK]
# Task controller configuration

# Task controller module, milltask.
TASK = milltask

# Execution period for milltask.
CYCLE_TIME = 0.010


[RS274NGC]
# RS274NGC interpreter configuration

# Interpreter variables file.
PARAMETER_FILE = linuxcnc.var

# Startup codes for the interpreter.
# The meaning of the currently set codes are:
# - G21: set the unit system to use millimeters
# - G40: turn tool compensation off
# - G90: set distance mode to absolute positioning
# - G94: set feed rate mode to units per minute
# - G64 P0.025: configure path blending with a deviation tolerance of 0.025
RS274NGC_STARTUP_CODE = G21 G40 G90 G94 G64 P0.025


[EMCMOT]
# Motion controller configuration

# Motion controller module, motmod.
# Not used by LinuxCNC directly, used in the HAL file.
EMCMOT = motmod

# Number of seconds to wait for the motion module
# to confirm receipt of messages from the task module.
COMM_TIMEOUT = 1.0

# Servo thread period in nanoseconds
# Not used by LinuxCNC directly, used in the HAL file.
SERVO_PERIOD = 1000000


[HAL]
# Hardware Abstraction Layer (HAL) configuration

# Add HAL user interface pins.
HALUI = halui

# HAL files to execute when starting LinuxCNC.
# Can be specified multiple times.
HALFILE = citic_gantry_robot.hal

# HAL files to execute after loading the graphical interface.
POSTGUI_HALFILE = gui_panel.hal

# HAL files to execute when closing LinuxCNC.
# SHUTDOWN = shutdown.hal


[HALUI]
# HAL user interface

# MDI_COMMAND can be specified multiple times.
# To execute it use the pin halui.mdi-command-NN,
# where NN is the command number.

# Go to zero position
MDI_COMMAND = G1 X0 Y0 Z0 F5000

# Go to stop position
MDI_COMMAND = G1 X5100 Y0 Z0 F5000


[KINS]
# Kinematics

# Number of joints (motors).
JOINTS = 4

# Kinematics module
# Not used by LinuxCNC directly, used in the HAL file.
KINEMATICS = trivkins coordinates=XXYZ kinstype=BOTH


[APPLICATIONS]
# Additional applications. Can be specified multiple times.
# APP=halscope 50000
# APP=halscope 100000


[TRAJ]
# Trajectory planner configuration

# Controlled axes. Possible values: X, Y, Z, A, B, C, U, V, W.
# An axis can be specified more than once, e.g., XXYZ.
COORDINATES = XXYZ

# Units for linear axes.
LINEAR_UNITS = mm

# Units for rotary axes.
ANGULAR_UNITS = degree

# Maximum linear velocity, in units per second.
MAX_LINEAR_VELOCITY = 600.0

# Maximum linear acceleration, in units per second^2.
MAX_LINEAR_ACCELERATION = 200.0


[EMCIO]
# Input/Output (I/O) controller configuration

# Input/output controller module.
EMCIO = io

# Period at which EMCIO will run.
CYCLE_TIME = 0.100


[AXIS_X]
# X axis configuration

# Note: The X axis motors (Igus MOT-EC-86-C-I-A) have a a maximum speed of
# 3000 rpm and a reduction gear with ratio 0.1. The X axis moves 144 mm/rev,
# therefore the maximum speed is: 144 * 0.1 * 3000 / 60 = 720.0 mm/s.

# Maximum axis velocity, in units per second.
MAX_VELOCITY = 600.0

# Maximum axis acceleration, in units per second^2.
MAX_ACCELERATION = 200.0

# Minimum limit for the axis, in machine units.
MIN_LIMIT = -5.0

# Maximum limit for the axis, in machine units.
MAX_LIMIT = 5300.0


[AXIS_Y]
# Y axis configuration

# Note: The Y axis motor (Igus MOT-EC-86-C-I-A) has a a maximum speed of
# 3000 rpm and a reduction gear with ratio 0.1. The X axis moves 144 mm/rev,
# therefore the maximum speed is: 144 * 0.1 * 3000 / 60 = 720.0 mm/s.

# Maximum axis velocity, in units per second.
MAX_VELOCITY = 600.0

# Maximum axis acceleration, in units per second^2.
MAX_ACCELERATION = 200.0

# Minimum limit for the axis, in machine units.
MIN_LIMIT = -5

# Maximum limit for the axis, in machine units.
MAX_LIMIT = 5200.0


[AXIS_Z]
# Z axis configuration

# Note: The Z axis motor (Igus MOT-AN-S-060-035-060-M-C-AAAC) has a a maximum
# speed of 1000 rpm. The Z axis moves 4 mm/rev, therefore the maximum speed is
# 4 * 1000 / 60 = 66.6 mm/s. However, since we run the motor at 24V instead of
# the maximum 48V, the torque is considerably reduced and the maximum actual
# speed is reduced to about 500 rpm, in this case the maximum speed is
# 4 * 500 / 60 = 33.3 mm/s.

# Maximum axis velocity, in units per second.
MAX_VELOCITY = 20.0

# Maximum axis acceleration, in units per second^2.
MAX_ACCELERATION = 80.0

# Minimum limit for the axis, in machine units.
MIN_LIMIT = -1050.0

# Maximum limit for the axis, in machine units.
MAX_LIMIT = 5


[JOINT_0]
# X1 motor configuration

# Motor type, LINEAR or ANGULAR.
TYPE = LINEAR

# Maximum following error, in machine units.
FERROR = 10

# Maximum following error at very slow speeds.
MIN_FERROR = 1

# Maximum motor velocity, in units per second.
MAX_VELOCITY = 50.0

# Maximum motor acceleration, in units per second^2.
MAX_ACCELERATION = 20.0

# Minimum motor limit, in machine units.
MIN_LIMIT = -5.0

# Maximum motor limit, in machine units.
MAX_LIMIT = 5300.0

# Position to which the joint will move when completing the homing process.
HOME = 0

# Used to define the 'home all' sequence.
# Note: the homing of the X joints must be synchronized, so we set their
# HOME_SEQUENCE options to -1. For more details check the LinuxCNC manual.
HOME_SEQUENCE = -1

# Home switch position, in machine units.
HOME_OFFSET = -15

# Initial homing search velocity, in units per second.
HOME_SEARCH_VEL = -25

# Final homing search velocity, in units per second.
HOME_LATCH_VEL = -5

# Final homing velocity, in units per second.
HOME_FINAL_VEL = 10

# Ignore limit switches during homing.
# Must be set to YES when using the same switch for limits and homing.
HOME_IGNORE_LIMITS = YES

# The switch is shared with another joint.
HOME_IS_SHARED = 0

# Use encoder index pulse for homing.
HOME_USE_INDEX = NO

# *****************************************
# Custom configuration: +-10V analog output
# *****************************************

# Maximum velocity in units per second.
ANALOGOUT_MAXLIM = 720

# Minimum velocity in units per second.
ANALOGOUT_MINLIM = -720

# Analog output scale. Vout = 10 * velocity / ANALOGOUT_SCALE.
# Maximum velocity in units per second that the motor can reach.
# Important: must be set to the same maximum speed configured
# in the motor controller in the drive profile section.
# Note: we set it negative to reverse the direction of the movement.
ANALOGOUT_SCALE = -720

# *****************************
# Custom configuration: Encoder
# *****************************

# Encoder scale. ENCODER_SCALE = counts / Position.
# The encoder does 1000 ppr (4000 cpr). The motor (Igus MOT-EC-86-C-I-A)
# has a reduction gear with ratio 0.1 and moves the axis at 144 mm/rev.
# Therefore the encoder scale is 4000 / (144 * 0.1) = 277.7778.
# Note: we set it negative to reverse the direction of the movement.
ENCODER_SCALE = -277.7778

# *************************
# Custom configuration: PID
# *************************

P = 40
I = 5
D = 0
FF0 = 0
FF1 = 1
FF2 = 0.01
BIAS = 0
DEADBAND = 0
MAX_OUTPUT = 0


[JOINT_1]
# X2 motor configuration

# Tipo de motor, LINEAR o ANGULAR.
TYPE = LINEAR

# Maximum following error, in machine units.
FERROR = 10

# Maximum following error at very slow speeds.
MIN_FERROR = 1
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

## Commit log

2025-07-14 Added initial documentation sources
    [mesa_7i96s_7i77_xy.hal, mesa_7i96s_7i77_xy.ini]
2025-07-15 Added linuxcnc simulation configuration
    [citic_gantry_robot_sim.hal, citic_gantry_robot_sim.ini, core_sim.hal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]
2025-07-15 Fixed repository link of the LinuxCNC motor control testbed in README.md
2025-07-22 Added English documentation and removed Spanish version
    Documentation was adapted from our LinuxCNC testbed project
    (https://github.com/GTEC-UDC/linuxcnc_testbed). The gantry robot is a
    similar system but with additional axes and joints, making the testbed
    documentation a suitable foundation.
    Updates required for the documentation:
    - Chapters 2 and 3: Update to reflect gantry robot differences
    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
    [mesa_7i96s_7i77_xy.hal, mesa_7i96s_7i77_xy.ini]
2025-07-25 Reviewed chapter 3 of documentation. Some images still need to be updated.
    [citic_gantry_robot.hal, citic_gantry_robot.ini, gui_panel.hal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]
2025-07-31 Improve configuration and parameters handling in calibration code
    The main changes are the following:
    **Configuration options:**
    - Replace separate alignment_init.json and bad_frames.json with unified config.json
    - Rename "bad_frames" to "skip_frames" for clarity
    - Add other configuration options for optimization parameters
    - Implement Pydantic models for the configuration in data.py
    **Calibration parameters:**
    - Replace numpy .npy files with single JSON file for calibration parameters
    - Implement CalibrationParams Pydantic model with alignment and correction parameters
    **Other changes:**
    - Add requirements.txt file.
    - Add --time-unit option in plot_errors.py to select the x-axis units (s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
2025-07-31 Replace 2025-04-23 measurements with 2025-04-09 ones
    The 2025-04-23 measurements were carried away using calibration
    with the calibxyzkins module. This means they cannot be used to
    analyze the error of the uncalibrated gantry robot. Moreover
    the results are incorrect because we made a mistake and used
    incorrect calibration parameters.
    The 2025-04-09 measurements were carried away without calibration,
    thus this is the baseline dataset for error analysis and evaluation
    of the calibration effectiveness.
    [take_gantry.csv, take_optitrack.csv]
2025-07-31 Improved plots in plot_errors_scatter.py
    - Adjusted figure size to 10x6.
    - Improved titles and labels names.
    - Modified x-axis limits for the Z fit line calculation from -1050 to -1100.
2025-07-31 Added README.md file to calibration code
2025-07-31 Fix HAL parameter names in calibxyzkins module
    [calibxyzkins.c, calibxyzkinsutils.c]
2025-07-31 Update images and minor review of mesa boards section in documentation chapter 3
2025-07-31 Update README.md of calibration code
2025-07-31 Add error analysis and calibration code documentation to project documentation
    This commit adds the documentation of the error analysis and calibration code to the project documentation. It was adapted from the README file of the code.
2025-07-31 Add igus-dryve configuration files for X1, X2, Y, and Z motor controllers
2026-06-15 Update documentation: bold vector/matrices and restructure inverse kinematics algorithm
2026-06-15 Update calibxyzkins: add missing stdbool imports
    [calibxyzkins.c, calibxyzkinsutils.c]
2026-06-15 Update calibration: reorder alignment transforms
2026-06-15 Update calibration: rename vector C to c in code and use bold matrices/vectors in README
2026-06-15 Rename inverse kinematics residual from f to r in docs and code
    Use r for the residual (Ax + Bx^2 + c - x') in the calibxyzkins documentation
    and the calib_xyz_inverse function.
    Also fix a debug printf that printed the f_norm pointer instead of its value.
2026-06-16 calibration: fix mypy and flake8 linting issues
2026-06-16 calibration: make Player class generic over frame data type to fix LSP violation
    The Player base class declared update() with a frame_data of type
    PlayerFrameData. Subclasses PointPlayer and MultiPointPlayer narrowed
    the type of frame_data, which broke Liskov substitution.
    To solve this we parametrize Player at the class level (Player[T: PlayerFrameData]).
    PointPlayer and MultiPointPlayer now subclass Player[PointFrameData] and
    Player[MultiPointFrameData], respectively.
2026-06-17 calibration: use column-vector convention for calibration matrices
2026-06-17 calibration: change "optitrack" to "OptiTrack"
2026-06-17 calibration: rename variables in get_processed_data for clarity
2026-06-17 calibration: add objective configuration and least-squares correction
    The optimization objective now can be configured to mean squared error
    or mean Euclidean distance in the "objective" setting. Because the
    correction transform is linear in A, B and c, the MSE objective is
    solved using least squares with numpy.linalg.lstsq. The alignment step
    and the mean-distance objective use scipy.optimize.minimize.
    The README was updated to document the new settings.
    The calibration.json and config.json measurement files were updated.
    This commit also fixes the following problems:
    - coord_mse now returns the true MSE. The previous coord_mse actually
    computed the mean distance.
    - The "calibration" ke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
2026-06-22 docs: fix Jacobian to column-vector convention in calibration page
2026-06-23 calibration: color error scatter points by cross axis in plot_errors_scatter.py
2026-06-23 calibration: rasterize scatter point cloud for PDF in plot_errors_scatter.py
2026-06-23 calibration: add per-row error limits and figure size options in plot_errors_scatter.py
2026-06-23 calibration: update config.json and calibration.json of 2025-04-09 measurements
    Update config.json to skip frames before the starting point (X=300, Y=300, Z=-1050).
2026-06-23 calibration: add mm unit to X and Y axes labels in plot_errors_scatter.py
2026-06-23 calibration: set default colormap to viridis in plot_errors_scatter.py
2026-06-23 calibration: add optional font override in plot_errors_scatter.py
2026-06-25 calibration: update plot_errors_probability.py script
2026-06-26 calibration: set max_rotation to null in config.json
2026-06-30 calibration: extract error statistics summary to dedicated print_errors_summary.py script
2026-06-30 calibration: format and linter fixes in print_errors_summary.py
2026-06-30 calibration: fix label in print_errors_summary.py
2026-06-30 calibration: add acceleration overlay in plot_errors.py
2026-06-30 calibration: add plot_marker_errors.py script
2026-06-30 calibration: update skip_frames ranges and regenerate calibration
    Added new frame ranges detected via plot_marker_errors where OptiTrack
    tracking quality degraded temporarily.
2026-06-30 calibration: configure log level to info in plot_errors_scatter.py
2026-09-28 calibration: reject OptiTrack outliers using a 5-sigma MAD threshold and regenerate calibration
2026-09-29 calibration: add drift, model comparison, and dataset validation scripts
2026-10-02 calibration: replace `Optional[X]` by `X | None` and organize imports
2026-10-02 calibration: replace mutable default arguments by `None` defaults
2026-10-02 calibration: add requirements-dev.txt file
2026-10-02 calibration: fix ruff and pyright warnings and errors
2026-10-02 calibration: add defaults.py with default file paths for the scripts
2026-10-05 calibration: generalize the correction model to degree n
2026-10-05 calibration: use a correction model of degree three for the 2025-04-09 measurement
2026-10-05 calibration: show the default values of all the options in the help of the scripts
2026-10-05 calibration: add a base class for the correction models and type hints to validate_dataset.py
2026-10-05 calibration: compare correction models of any degree, with an optional validation on the dataset
2026-10-05 calibration: review some of the dataset scripts to improve their readability
2026-10-05 calibration: fix the margin of the samples used to estimate the dataset clock drift
2026-10-05 calibration: warn when a minimization does not converge
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2026-10-06 calibxyzkins: implement general correction model
    The kinematics now implement the general model
    [x, y, z]^T = c + sum_{k=1}^{n} A_k * [jx^k, jy^k, jz^k]^T
    where [x, y, z] are the axes coordinates, [jx, jy, jz] are the joints
    positions, A_k are the transformation matrices, c is an offset vector,
    and n is the degree of the transformation.
    The degree n is set with the "degree" module parameter (1 to
    CALIB_XYZ_MAX_DEGREE, default 1). The HAL parameters of the matrices
    are named calibxyzkins.calib-a<k>.*, with <k> the corresponding degree
    number.
    The changes include:
    - Tests and README updated for the new model.
    - calibxyzlib: forward transformation, Jacobian and invertibility check
    for a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
2026-10-08 calibration: add a script to check the convergence of the inverse kinematics solver
    check_inverse_kinematics.py runs the Newton-Raphson iteration of the
    calibxyzkins module on a grid of target axis positions and reports the
    distance from the initial estimate to the solution, the steps needed and
    the residual left.
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2026-10-09 calibration: rename CorrectionParams to PolynomialCorrection
    - CorrectionParams -> PolynomialCorrection
    - Model of compare_correction_models.py -> FullPolynomialModel
    - fit_correction_params, load_correction_params, correction_params_from_coef
    -> fit_correction, load_correction, correction_from_coef
    - fit_correction of calibration_clock_drift_impact.py
    -> fit_correction_with_drift
    - Rename the variables that hold the model to correction
2026-10-09 calibration: align the OptiTrack data with numpy arrays instead of dataframes
    - coord_align -> coord_align_array, which takes arrays of positions
    - coord_calibrate removed: the scripts call the apply method of the model
    - coord_mse, coord_mean_distance of coordinates_utils.py
    -> samples_mse, samples_mean_distance of data.py
    - The rotation about the y axis follows the scipy convention, so its angle
    changes sign in the alignment parameters. calibration.json and its copy
    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
2026-10-09 calibration: remove coordinates_utils.py, no longer used
2026-10-09 calibration: split get_processed_data into fit_alignment and fit_correction_with_config
2026-10-09 calibration: remove init_params from CalibrationCorrectionConfig
2026-10-10 calibration: store the alignment as an AlignmentTransform instead of an array
2026-10-10 calibration: remove the mean_distance objective and update fit_correction to exclude NaN samples
2026-10-10 calibration: use Kabsch algorithm for alignment
2026-10-10 calibration: give the OptiTrack capture start time its time zone
    The OptiTrack files give the capture start as a local time without time zone,
    and it was converted with the time zone of the computer running the scripts.
    It now takes the time zone of the OptiTrack computer (OPTITRACK_TZ).
2026-10-13 calibration: validate the dataset without skipping the first 6 s
2026-10-15 calibration: cubic fit for the in-plane trends of plot_errors_scatter
2026-10-15 calibration: pass NumPy arrays to set_data_3d in the players
    With matplotlib 3.11, Line3D.draw fails with "AttributeError: 'list'
    object has no attribute 'shape'" when the 3D data are lists that contain
    NaN, as in the frames where the rigid body or a marker is missing.
2026-10-15 calibration: add time-aligned marker count and log rejected intervals
    Add M.COUNT, the number of markers reconstructed, shifted with the
    alignment like the positions. Remove the frame, ERR.* and centroid
    columns, which the alignment did not shift: plot_marker_errors.py now
    computes the marker errors from the aligned positions, and the plots
    use the row of the processed data instead of the frame.
2026-10-15 calibration: add SKIPPED/REJECTED columns to return data of get_processed_data
2026-10-15 calibration: add print_rejected_samples.py script
2026-10-15 calibration: encoder position instead of commanded position in comments
2026-10-27 calibration: rename calibration_clock_drift_impact.py to check_clock_drift_impact.py
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2026-10-27 calibration: move column names, fill_gaps and rms3d to data.py
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

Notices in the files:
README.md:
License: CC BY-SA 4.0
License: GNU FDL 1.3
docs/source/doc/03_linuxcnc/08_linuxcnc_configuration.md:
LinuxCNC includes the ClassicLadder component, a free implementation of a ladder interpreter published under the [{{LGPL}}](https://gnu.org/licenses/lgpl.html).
